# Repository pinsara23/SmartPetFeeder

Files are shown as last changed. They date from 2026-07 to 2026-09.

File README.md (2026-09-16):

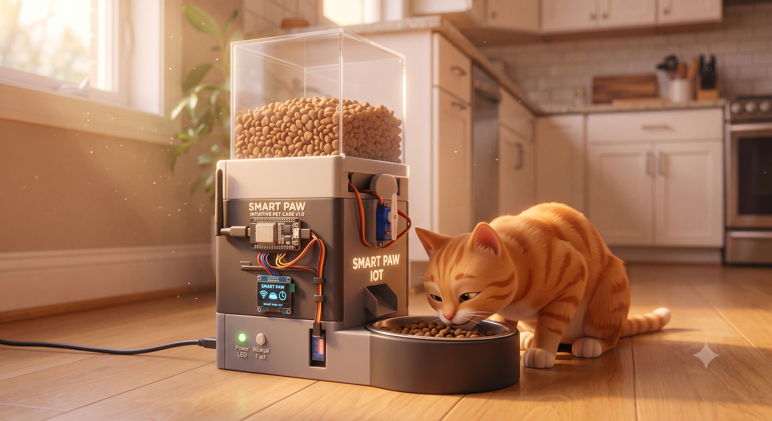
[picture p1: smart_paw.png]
Smart pet feeding system


# Smart Pet Feeder

A smart, automated pet feeding system built using an **ESP32** microcontroller. This project uses a load cell for precise food measurement, servos for dispensing, and a keypad-driven LCD menu for scheduling and portion control. 

The firmware is developed using **PlatformIO** and the Arduino framework.

## Features
- **Real-Time Clock:** Enter the current time in `HHMM` format during boot. The clock runs in firmware and wraps at midnight.
- **Precise Portion Control:** Enter a target weight from 1 to 1000 g. The HX711 load cell controls the food-container servo until the measured amount is within 3 g of the target.
- **Scheduled Feeding:** Configure two daily feeding times, `F1` and `F2`.
- **Two-Stage Feeding:** Food is first dispensed into the measuring chamber, then released into the bowl by a separate servo.
- **RFID Authentication:** An RFID scan authorizes early release during the configured release window. Release also occurs automatically at the exact scheduled minute as a fail-safe.
- **Jam Recovery:** If the measured weight does not increase by at least 0.5 g for 2 seconds, the food gate performs an automatic shake sequence before resuming.
- **Interactive UI:** A 20x4 I2C LCD and 4x4 keypad provide the setup, scheduling, weight, and reset controls.

## Hardware Components
- ESP32 Development Board
- 20x4 I2C LCD Display
- 4x4 Matrix Keypad
- Load Cell + HX711 Amplifier
- PCA9685 I2C PWM Servo Driver
- 2x Servos (for the food container and measurement chamber)
- MFRC522 RFID Reader

## Pin Configuration (ESP32)

| Component | Pins Used |
| --- | --- |
| **PCA9685 (Servos)**  | I2C (SDA, SCL) |
| **Keypad Rows** | GPIO 32, 33, 2, 4 |
| **Keypad Cols** | GPIO 12, 13, 16, 17 |
| **HX711 (Load Cell)** | DT: GPIO 25, SCK: GPIO 26 |
| **RFID (MFRC522)** | SS: GPIO 5, RST: GPIO 15 |
| **LCD (I2C)** | SDA, SCL (Default I2C pins) |

## ESP32 Pinout

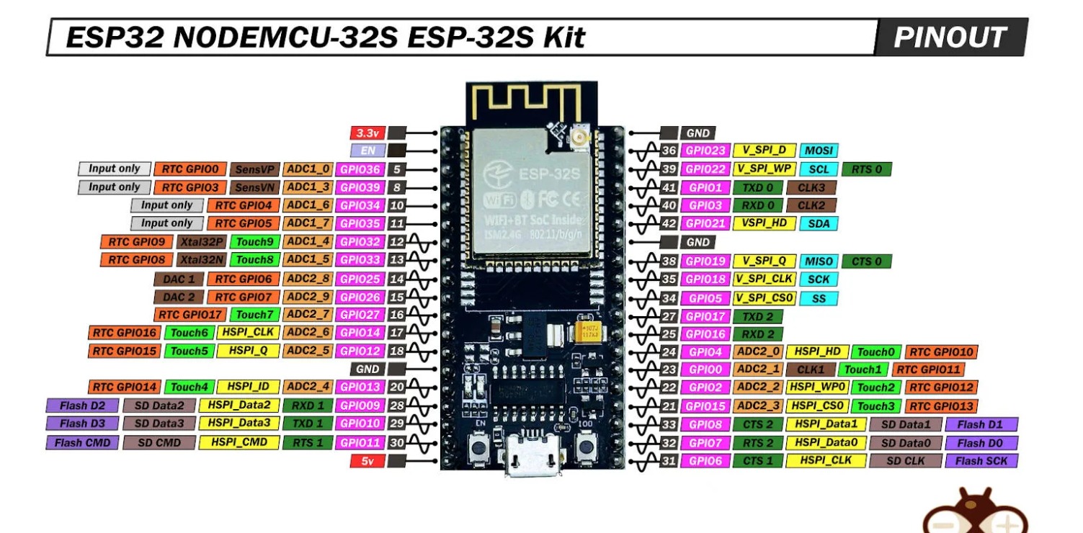
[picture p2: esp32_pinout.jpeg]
ESP32 pinout


## Software Dependencies
The following libraries are required (automatically managed via `platformio.ini`):
- `marcoschwartz/LiquidCrystal_I2C`
- `chris--a/Keypad`
- `bogde/HX711`
- `adafruit/Adafruit PWM Servo Driver Library`
- `miguelbalboa/MFRC522`

## Usage / Menu Navigation

1. **Boot:** Enter the current time (HHMM) using the keypad and press `#` to confirm.
2. **Dashboard (Default Screen):** Displays Target Weight (TW), Current Weight (CW), Feed Times (F1 & F2), and the current Time.
3. **Menu System:** Press `C` from the dashboard to enter the inputs menu.
   - **Press A:** Set Target Weight (1-1000 g). Enter the value and confirm with `#`.
   - **Press B:** Set Feed Times. Enter Feed 1 and Feed 2 in `HHMM` format, confirming each with `#`. Hours must be `00-23` and minutes must be `00-59`.
   - **Press C:** Go back to the dashboard.
   - **Press *:** Reset all settings and values at any time.

## Current Feeding Logic

The firmware treats each scheduled feeding as two separate operations:

1. **Fill the measuring chamber:**
   - **Feed 1:** The food-container servo dispenses from 3 to 5 minutes before the scheduled time.
   - **Feed 2:** The food-container servo dispenses from 35 to 90 minutes before the scheduled time.
   - Outside the active window, or when no target weight is configured, the food gate remains closed.
2. **Release food into the bowl:**
   - **Feed 1:** The chamber can open during the 2 minutes before feeding when RFID is detected.
   - **Feed 2:** The chamber can open during the 30 minutes before feeding when RFID is detected.
   - Once RFID has been detected in the release window, authorization remains active until that feeding event. At the exact scheduled time, the chamber opens even without RFID.

The schedule calculations support crossing midnight. Each feeding time is compared with the current time as minutes from midnight, and a feeding time that has passed is treated as the next day's event. Each RFID authorization flag is cleared after its release window ends, so an old scan cannot authorize a later feeding.

### Portion and Servo Control

- While more than 5 g remains, the food gate uses the normal 18-degree opening.
- With approximately 3 to 5 g remaining, it uses 10-degree pulses. Each pulse stays open for 120 ms, then the system waits 700 ms for the load cell reading to settle.
- When the measured amount is within 3 g of the target, dispensing stops and the food gate closes.
- During jam recovery, the gate alternates between 5 and 40 degrees for up to 6 steps, with 180 ms between steps, then returns to normal dispensing.
- The measuring-chamber servo is closed at 0 degrees and opened at 100 degrees.
- If dispensing is not currently scheduled, the food gate is closed and jam tracking is reset.
- The dispensing state machine reports `IDLE`, `NORMAL FLOW`, `PRECISION PULSE`, `SETTLING`, or `COMPLETE` through the serial monitor.

Weight readings are refreshed approximately every 150 ms using two HX711 samples. Negative readings are clamped to zero. The LCD dashboard shows the target weight, current weight, both feed times, current time, and the current dispensing status. At each scheduled minute, the firmware also prints a feed-time trigger message to the serial monitor.

## Calibration
Load cell calibration can be adjusted dynamically via the Serial Monitor at 115200 baud. The initial calibration factor is 1015.
- Send `+` to increase the calibration factor by 10.
- Send `-` to decrease the calibration factor by 10.

## Reset Behavior

Press `*` from any menu to clear the target weight, both feed times, and temporary input. The food gate and measuring chamber close, the dispensing state is reset, and the dashboard is displayed.

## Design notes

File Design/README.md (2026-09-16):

# 🐾 Smart PAW – Automatic Pet Feeder Mechanical Design

Smart PAW is an automated pet feeding system designed to dispense a predefined amount of food while controlling access to the feeding area.

This repository contains the mechanical/CAD design of the Smart PAW pet feeder.

The enclosure and internal mechanisms were designed to support the electronic components of the system, including:

- ESP32 microcontroller
- Load cells with HX711 modules
- Servo motors
- RFID reader
- PCA9685 servo controller
- 20×4 LCD display
- 4×4 keypad

The complete system combines embedded electronics, sensors, servo control, weight measurement, RFID access control, and mechanical design.

---

## 📸 Smart PAW CAD Design

Smart PAW CAD Design

The design contains three main sections:

1. Food Storage Container
2. Food Measuring / Dispensing Chamber
3. Pet Feeding Area

---

## 🏗️ Mechanical Design Overview

### 1. Food Storage Container

The upper section of the feeder acts as the main food storage hopper.

Food is stored here until the feeding process begins.

The bottom of the container guides the food toward the first servo-controlled gate.

        Food Storage
             │
             ▼
      Servo Controlled Gate
             │
             ▼
      Measuring Chamber

The sloped walls help guide food toward the dispensing opening using gravity.

---

### 2. First Servo Gate – Food Dispensing

A servo motor controls the opening between the food storage container and the measuring chamber.

When food is requested, the ESP32 gradually opens the servo gate.

Food falls into the measuring chamber while the system continuously monitors its weight.

The software uses different servo movements to improve dispensing accuracy and reduce food jams.

Features include:

- Small initial servo opening
- Gradual food dispensing
- Anti-jam servo movement
- Automatic stopping near the target weight

---

## ⚖️ Food Measuring Chamber

The middle section acts as the food measurement chamber.

Load cells installed underneath the chamber measure the amount of food that has been dispensed.

The load cells are connected to HX711 load-cell amplifier modules.

Food Hopper
     │
     ▼
Servo Gate
     │
     ▼
┌──────────────────┐
│ Measuring Chamber│
│                  │
│   Food + Weight  │
└──────────────────┘
        │
    Load Cells
        │
      HX711
        │
      ESP32

The ESP32 compares the measured weight with the target weight entered by the user.

For example:

Target Weight = 40 g

Current Weight = 10 g
→ Continue dispensing

Current Weight = 30 g
→ Reduce food flow

Current Weight = 38 g
→ Stop dispensing

A small tolerance is used so that the system does not continuously attempt to reach an exact measurement.

---

## 🔄 Anti-Jam Mechanism

Dry pet food can occasionally become stuck near the dispensing opening.

To reduce this problem, the feeder uses a software-controlled anti-jam mechanism.

If the measured weight does not increase sufficiently after opening the dispensing gate, the servo performs small repeated movements.

Open
 ↓
Check Weight
 ↓
No Significant Change
 ↓
Small Close / Open Movement
 ↓
Check Weight Again

This helps move food without requiring the user to manually shake the feeder.

---

## 3. Second Servo Gate – Food Release

After the required amount of food has been measured, a second servo-controlled gate releases the food.

The food falls from the measuring chamber onto the lower feeding tray/chute.

Measuring Chamber
        │
        ▼
 Second Servo Gate
        │
        ▼
   Feeding Chute
        │
        ▼
      Pet Bowl

This separates the measurement process from the final feeding process.

---

## 🐕 RFID Controlled Access

The Smart PAW system also includes RFID-based access control.

An RFID tag can be attached to the pet's collar.

When an authorized RFID tag is detected, the system can allow access to the food area.

This can help prevent other pets from accessing food intended for a particular pet.

---

## 🧠 System Working Principle

The complete feeding process is:

User Enters Required Food Weight
                │
                ▼
         ESP32 Starts Feeding
                │
                ▼
      First Servo Gate Opens
                │
                ▼
      Food Enters Measuring Chamber
                │
                ▼
        Load Cells Measure Weight
                │
                ▼
      Target Weight Reached?
          │             │
         NO            YES
          │             │
          ▼             ▼
 Continue Dispensing   Stop Servo
          │             │
          │             ▼
          │      Open Second Gate
          │             │
          └─────────────▼
                   Food Released
                         │
                         ▼
                      Pet Bowl

---

## 🔧 Main Hardware

| Component | Purpose |
|---|---|
| ESP32 | Main system controller |
| HX711 | Load cell signal amplifier |
| Load Cells | Measure food weight |
| MG996R Servo | Control food gates |
| PCA9685 | Servo motor controller |
| RFID Reader | Identify authorized pet |
| RFID Tag | Pet identification |
| 20×4 I2C LCD | Display system information |
| 4×4 Keypad | Enter target food weight |
| 5V Power Supply | Power the system |

---

## ⚙️ Main Mechanical Components

The CAD design includes:

- Main outer enclosure
- Upper food storage hopper
- Sloped food guide
- Food dispensing opening
- First servo mounting location
- Food measuring chamber
- Load-cell mounting area
- Second servo mounting location
- Food release mechanism
- Lower feeding chute
- Electronics mounting areas
- Front and side structural panels

---

## 💡 Design Goals

The mechanical design was developed with several goals:

- Compact construction
- Gravity-assisted food movement
- Controlled food dispensing
- Accurate food measurement
- Reduced food jamming
- Easy servo integration
- Easy electronics installation
- Simple assembly
- Low-cost construction
- Automated pet access

---

## 📂 Suggested Repository Structure

Smart-PAW-Mechanical-Design/
│
├── README.md
│
├── CAD/
│   ├── parts/
│   └── assembly/
│
├── STL/
│   └── printable-parts/
│
├── drawings/
│   └── technical-drawings/
│
├── images/
│   ├── smart-paw-design.jpg
│   ├── front-view.jpg
│   ├── side-view.jpg
│   └── assembly-view.jpg
│
└── docs/
    └── design-notes.md

The exact folders can be changed depending on which CAD, STL, STEP, or drawing files are available.

---

## 🚀 Future Improvements

Possible future improvements include:

- Improved food-flow geometry
- Modular removable food container
- Easier cleaning mechanism
- Improved servo gate design
- Fully 3D-printable components
- Additional load-cell support
- Improved RFID antenna placement
- Adjustable feeding tray
- Enclosure for electronic components
- Detection of low food level
- Mobile application integration
- Wi-Fi based feeding control
- Feeding history and statistics

---

## 🔗 Related Smart PAW Development

The mechanical design is only one part of the complete Smart PAW project.

The overall system combines:

Mechanical Design
       +
ESP32 Firmware
       +
Weight Measurement
       +
Servo Control
       +
RFID Identification
       +
User Interface
       =
   Smart PAW

---

## 🎯 Project Purpose

Smart PAW was developed as a practical embedded systems project that combines mechanical design, electronics, sensors, actuators, and software into a single automated pet feeding system.

The project demonstrates concepts including:

- Embedded system development
- ESP32 programming
- Sensor interfacing
- Load-cell measurement
- Closed-loop control
- Servo motor control
- RFID identification
- Mechanical CAD design
- Hardware/software integration

---

## 👨‍💻 Author

Pinsara Sarathchandra

Computer Engineering Undergraduate

---

## 📜 License

This project is intended for educational and research purposes.

If you plan to reuse or modify the design, please provide appropriate credit to the original project.

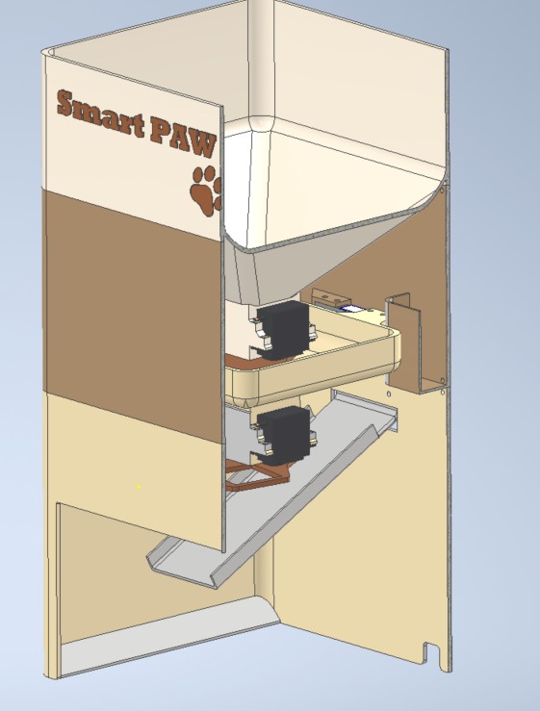
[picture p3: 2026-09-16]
Design/images/side_view_cut.jpeg

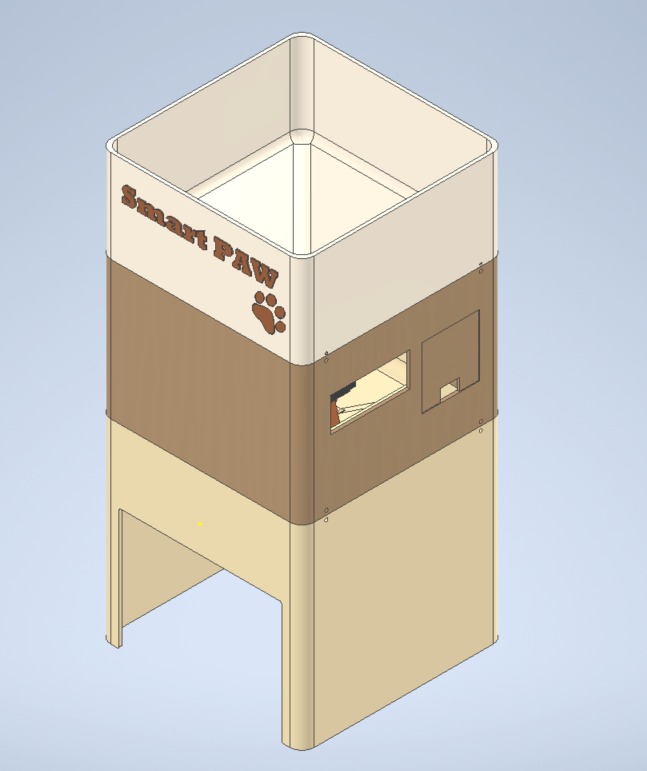
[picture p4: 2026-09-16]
Design/images/side_view.jpeg

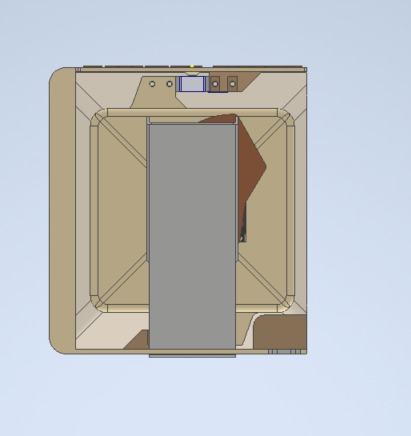
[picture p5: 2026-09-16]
Design/images/bottom_view.jpeg

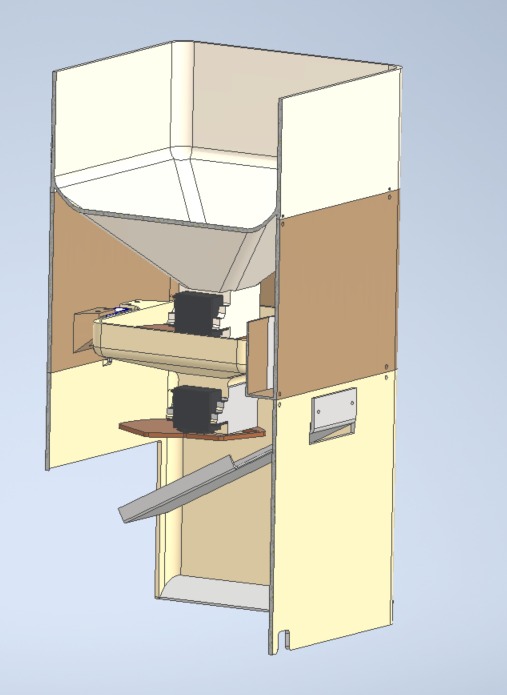
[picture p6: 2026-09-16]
Design/images/detailed_view.jpeg

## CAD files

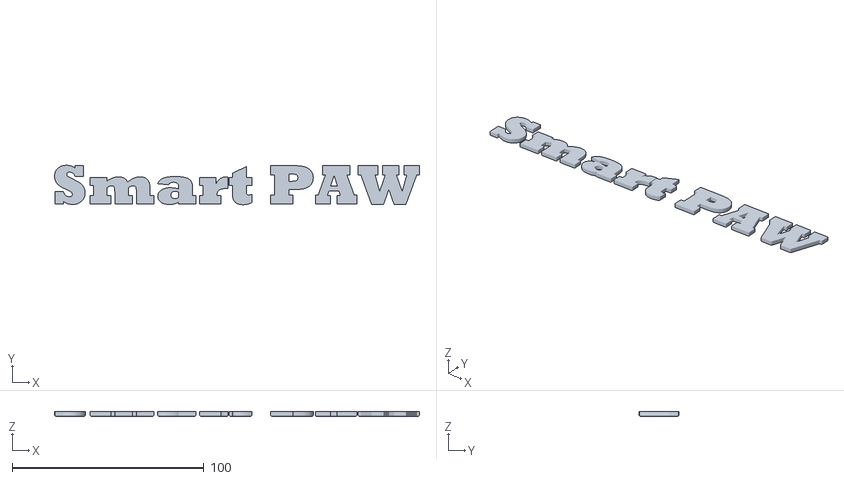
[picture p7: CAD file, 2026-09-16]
Design/stl/P1_name.stl
190.2 x 20.7 x 2.40

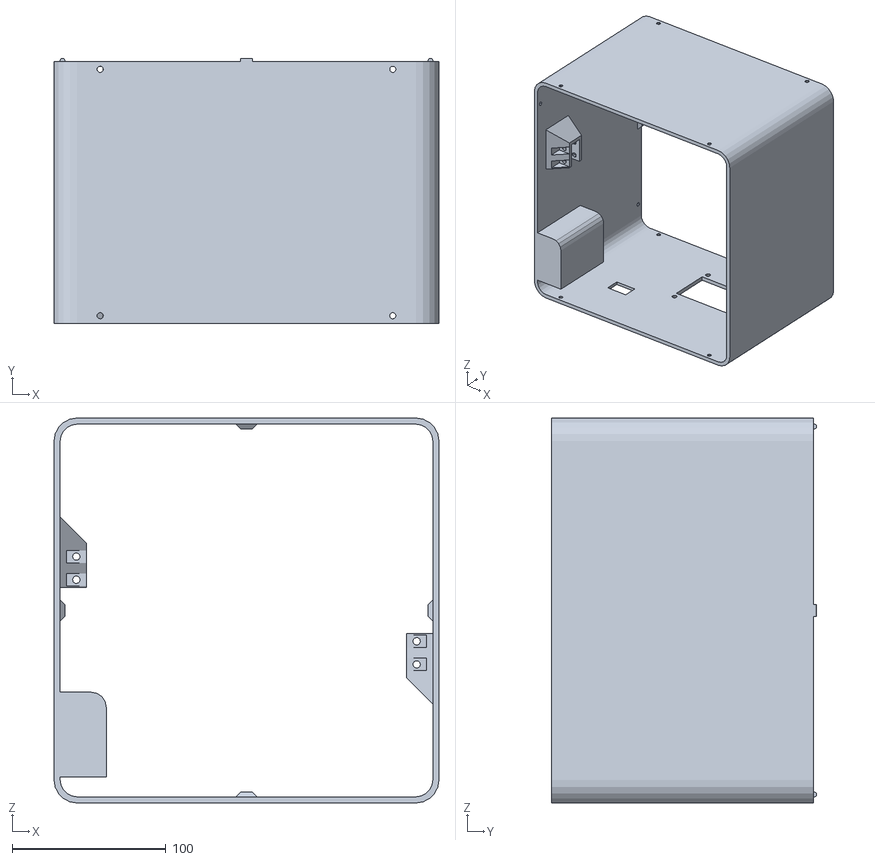
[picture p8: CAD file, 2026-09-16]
Design/stl/P1_middle.stl
250.0 x 172.0 x 250.0

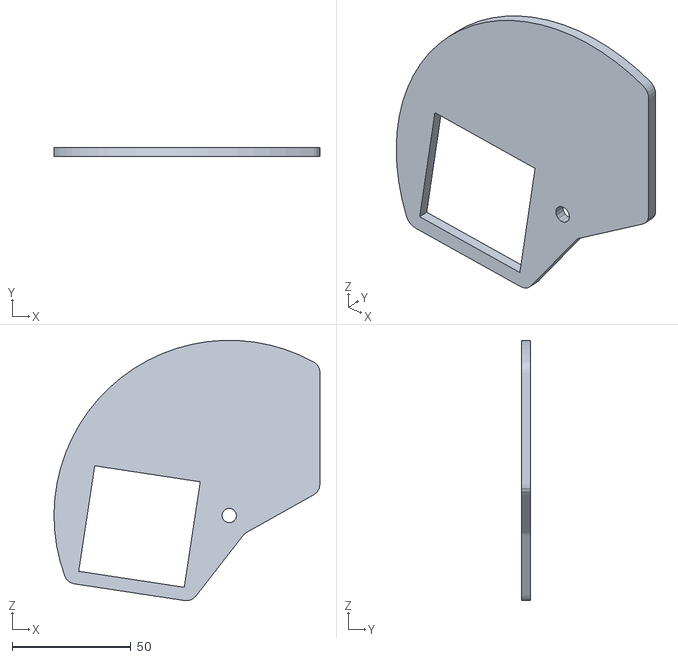
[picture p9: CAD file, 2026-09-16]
Design/stl/Servo_Lid.stl
112.2 x 4.00 x 109.7

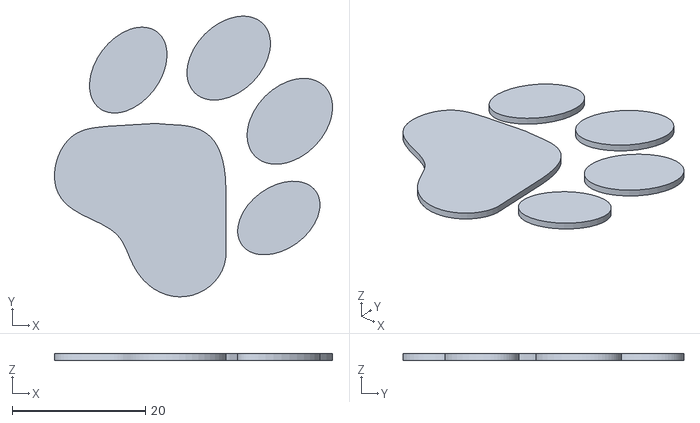
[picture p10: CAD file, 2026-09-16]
Design/stl/paw.stl
41.8 x 42.2 x 1.00

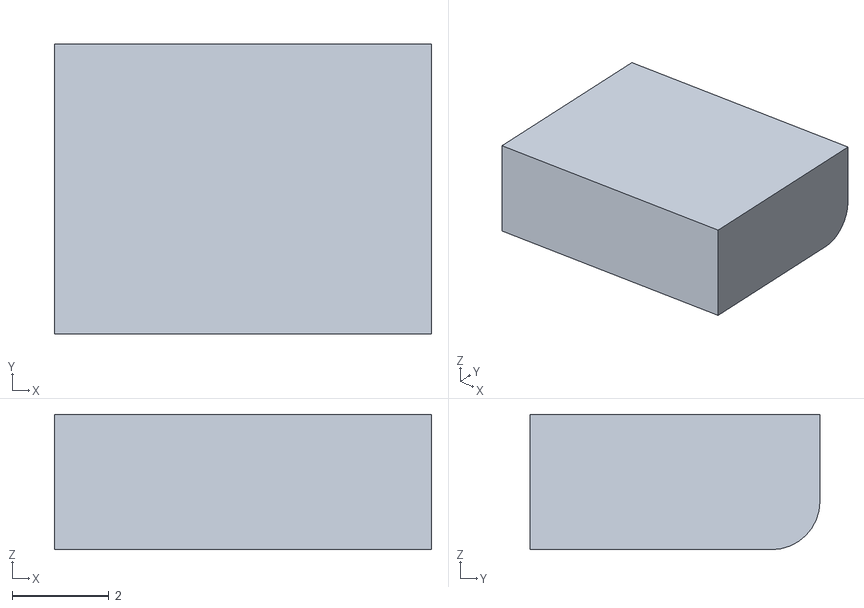
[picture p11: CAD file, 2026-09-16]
Design/stl/holder(x3).stl
7.80 x 6.00 x 2.80

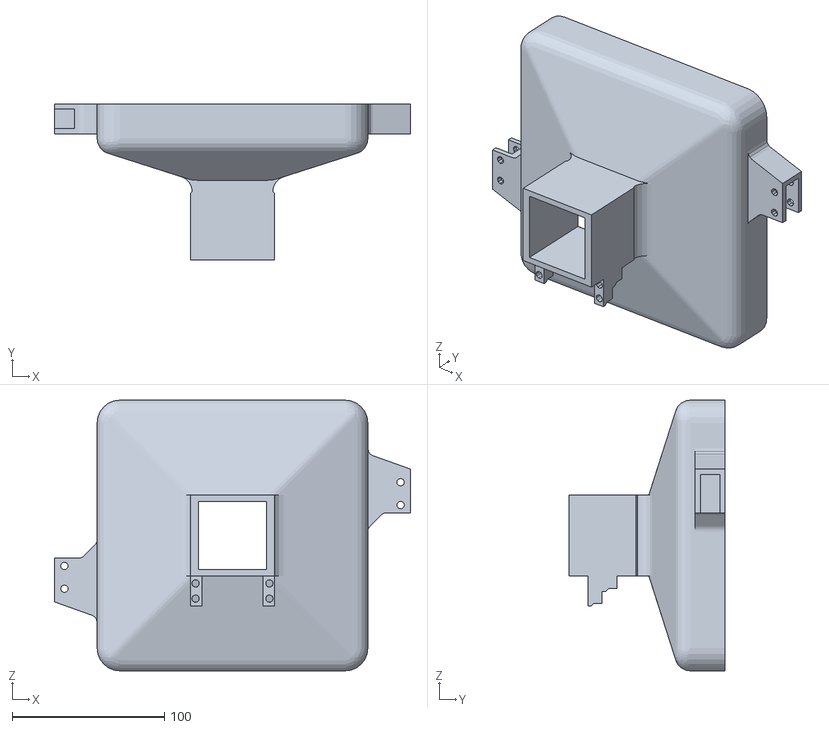
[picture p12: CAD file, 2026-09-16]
Design/stl/P2_middle.stl
234.0 x 102.3 x 178.0

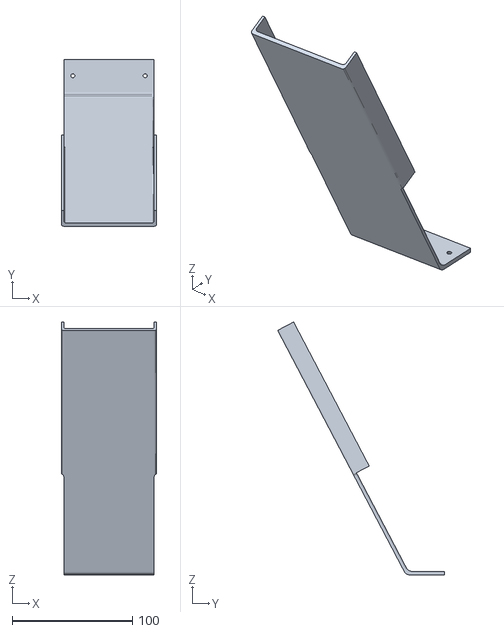
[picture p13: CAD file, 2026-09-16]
Design/stl/slide.stl
79.0 x 138.4 x 210.0

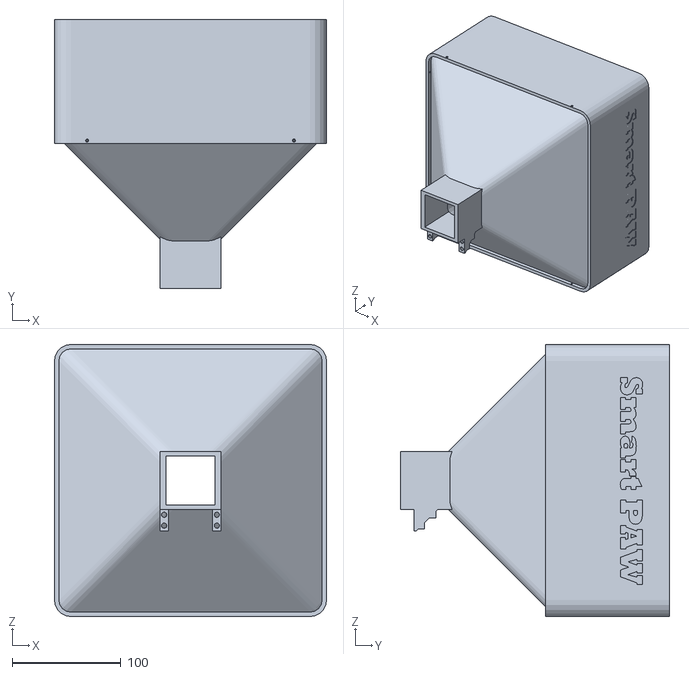
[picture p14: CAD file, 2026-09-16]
Design/stl/P1_up.stl
250.0 x 247.3 x 250.0

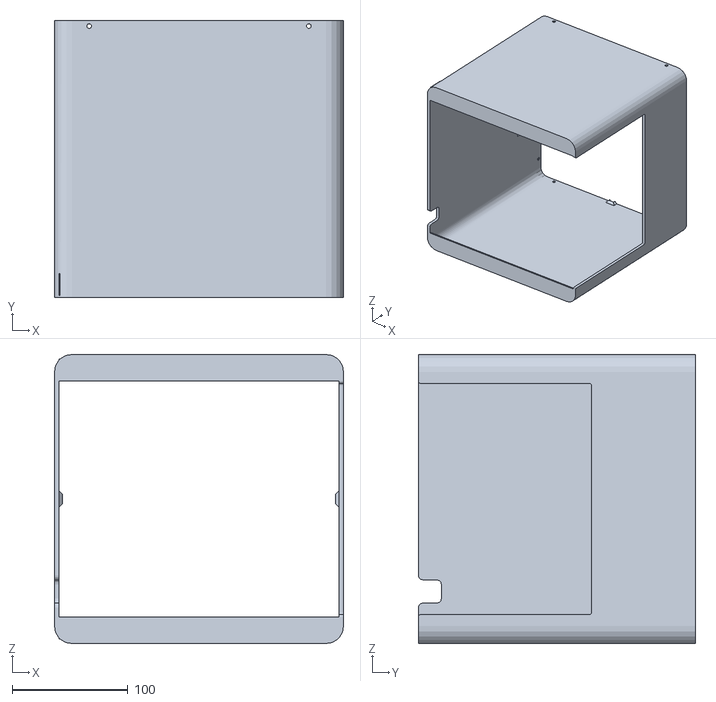
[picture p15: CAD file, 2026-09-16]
Design/stl/P1_Down.stl
250.0 x 240.0 x 250.0

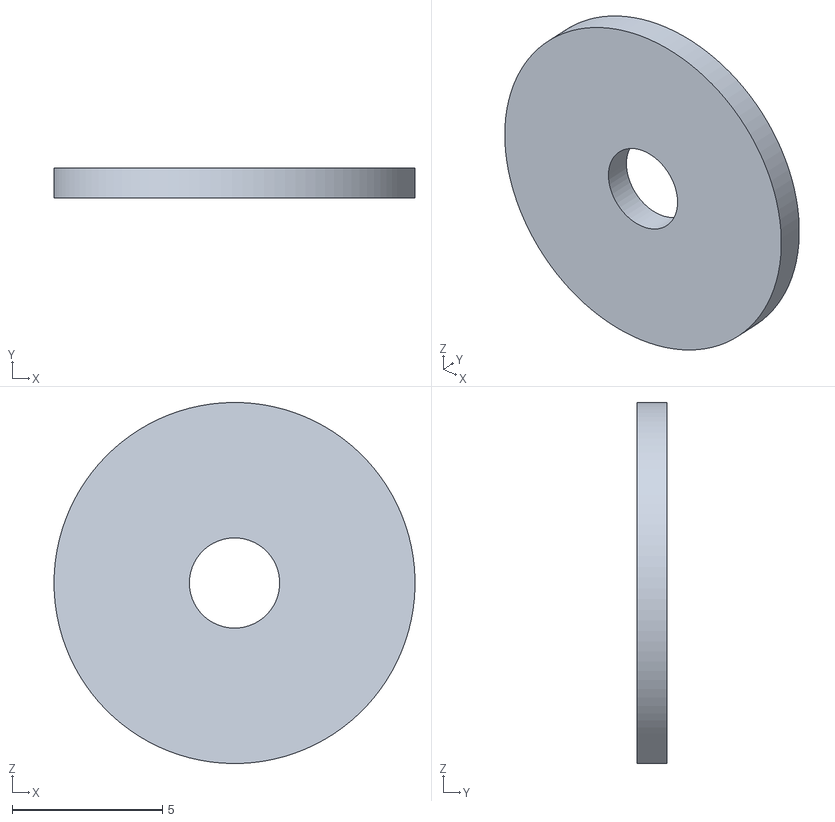
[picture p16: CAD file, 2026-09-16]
Design/stl/washer_for_P3_Lid.stl
12.0 x 1.00 x 12.0

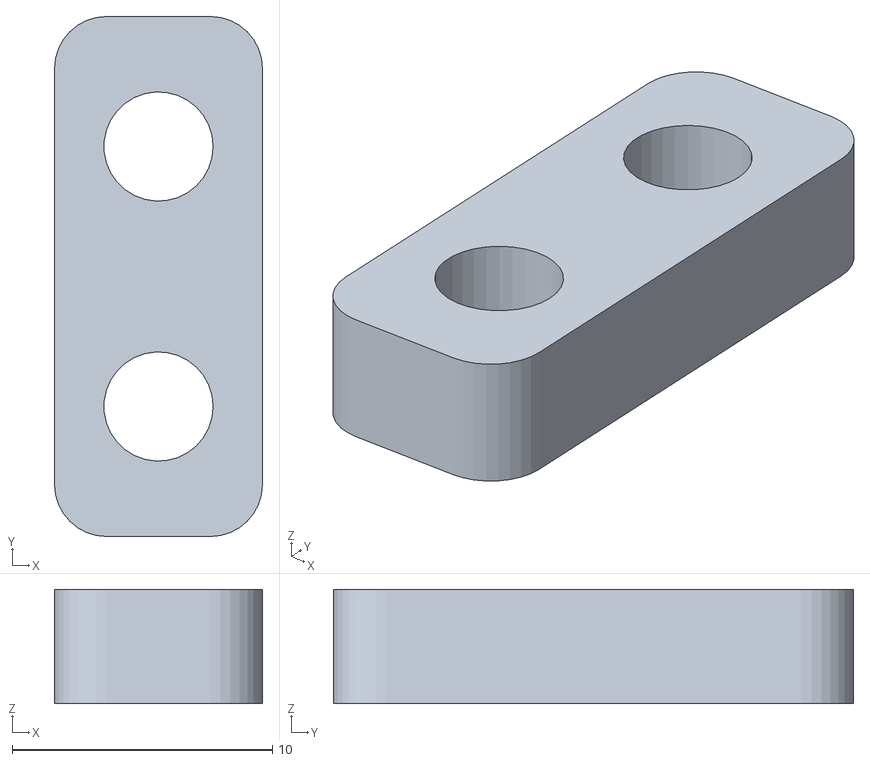
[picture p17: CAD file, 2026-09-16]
Design/stl/screw(x15).stl
8.00 x 20.0 x 4.40

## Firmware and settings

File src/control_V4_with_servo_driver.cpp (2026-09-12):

#include <Wire.h>
#include <LiquidCrystal_I2C.h>
#include <Keypad.h>
#include "HX711.h"
#include <Adafruit_PWMServoDriver.h>
#include <SPI.h>
#include <MFRC522.h>


// ============================================================
// RFID
// ============================================================

const int RST_PIN = 15;
const int SS_PIN = 5;

MFRC522 mfrc522(SS_PIN, RST_PIN);


// ============================================================
// PCA9685 SERVO DRIVER
// ============================================================

Adafruit_PWMServoDriver pwm = Adafruit_PWMServoDriver();

const int foodContainerPin = 0;
const int measureChamberPin = 1;


// Convert servo angle to PCA9685 pulse
int angleToPulse(int angle)
{
    return map(angle, 0, 180, 102, 491);
}


// ============================================================
// FOOD CONTAINER SERVO SETTINGS
// ============================================================

const int FOOD_CLOSED_ANGLE = 0;

// Normal small opening
const int FOOD_NORMAL_ANGLE = 18;

// Small opening for final dispensing
const int FOOD_PULSE_ANGLE = 10;


// ============================================================
// ANTI-JAM SETTINGS
// ============================================================

const int SHAKE_OPEN_ANGLE = 40;
const int SHAKE_CLOSE_ANGLE = 5;

const unsigned long SHAKE_STEP_TIME = 180;

const int MAX_SHAKE_STEPS = 6;


// ============================================================
// MEASURING CHAMBER SERVO
// ============================================================

const int measureChamberOpenAngle = 100;
const int measureChamberCloseAngle = 0;


// ============================================================
// DISPENSING SETTINGS
// ============================================================

// Enter precision mode when 5 g remains
const float PRECISION_MARGIN = 5.0;


// IMPORTANT:
// If target-current <= 3g,
// consider the amount acceptable.
const float TARGET_TOLERANCE = 3.0;


// Precision pulse duration
const unsigned long PULSE_OPEN_TIME = 120;


// Wait for food/load cell to settle
const unsigned long SETTLE_TIME = 700;


// ============================================================
// JAM DETECTION
// ============================================================

const float MIN_WEIGHT_PROGRESS = 0.5;

const unsigned long JAM_DETECT_TIME = 2000;


float lastProgressWeight = 0.0;

unsigned long lastProgressTime = 0;


bool clearingJam = false;

int shakeStep = 0;

unsigned long shakeTimer = 0;


// ============================================================
// DISPENSING STATE
// ============================================================

enum DispenseState
{
    DISPENSE_IDLE,
    DISPENSE_NORMAL,
    DISPENSE_PULSE_OPEN,
    DISPENSE_SETTLING,
    DISPENSE_COMPLETE
};


DispenseState dispenseState = DISPENSE_IDLE;

unsigned long dispenseTimer = 0;


// ============================================================
// LCD
// ============================================================

LiquidCrystal_I2C lcd(0x27, 20, 4);


// ============================================================
// KEYPAD
// ============================================================

const byte ROWS = 4;
const byte COLS = 4;


char hexaKeys[ROWS][COLS] =
{
    {'1', '2', '3', 'A'},
    {'4', '5', '6', 'B'},
    {'7', '8', '9', 'C'},
    {'*', '0', '#', 'D'}
};


byte rowPins[ROWS] =
{
    32, 33, 2, 4
};


byte colPins[COLS] =
{
    12, 13, 16, 17
};


Keypad customKeypad =
    Keypad(
        makeKeymap(hexaKeys),
        rowPins,
        colPins,
        ROWS,
        COLS
    );


// ============================================================
// HX711
// ============================================================

#define DT 25
#define SCK 26


HX711 scale;

float calibration_factor = 1015;


// ============================================================
// CLOCK
// ============================================================

int hours = 18;
int minutes = 23;
int seconds = 0;

unsigned long lastSecondUpdate = 0;


// ============================================================
// WEIGHT UPDATE
// ============================================================

unsigned long lastWeightUpdate = 0;

const unsigned long WEIGHT_UPDATE_INTERVAL = 150;


// ============================================================
// LCD UPDATE
// ============================================================

unsigned long lastLCDUpdate = 0;

const unsigned long LCD_UPDATE_INTERVAL = 500;


// ============================================================
// SERIAL UPDATE
// ============================================================

unsigned long lastSerialUpdate = 0;

const unsigned long SERIAL_UPDATE_INTERVAL = 1000;


// ============================================================
// WEIGHT VARIABLES
// ============================================================

String inputWeight = "";

int targetWeight = 0;

float currentWeightDisplay = 0.0;


// ============================================================
// MENU STATE
// ============================================================

enum MenuState
{
    INITIAL_TIME_SETUP,
    DEFAULT_SCREEN,
    INPUTS_MENU,
    WEIGHT_INPUT,
    TIME_SLOT_1,
    TIME_SLOT_2
};


MenuState currentState = INITIAL_TIME_SETUP;


// Feeding times in minutes from midnight
int feedTime1 = -1;
int feedTime2 = -1;


String inputTime = "";


// ============================================================
// FOOD SERVO
// ============================================================

void setFoodGate(int angle)
{
    static int previousAngle = -1;

    if (angle != previousAngle)
    {
        pwm.setPWM(
            foodContainerPin,
            0,
            angleToPulse(angle)
        );

        previousAngle = angle;

        Serial.print("Food Servo: ");
        Serial.print(angle);
        Serial.println(" deg");
    }
}


// ============================================================
// MEASURING CHAMBER SERVO
// ============================================================

void setMeasureChamber(int angle)
{
    static int previousAngle = -1;

    if (angle != previousAngle)
    {
        pwm.setPWM(
            measureChamberPin,
            0,
            angleToPulse(angle)
        );

        previousAngle = angle;

        Serial.print("Measure Servo: ");
        Serial.print(angle);
        Serial.println(" deg");
    }
}


// ============================================================
// DISPLAY TIME
// ============================================================

void displayTimeOnLCD()
{
    if (
        currentState == DEFAULT_SCREEN ||
        currentState == INITIAL_TIME_SETUP
    )
    {
        return;
    }


    lcd.setCursor(0, 3);


    if (hours < 10)
        lcd.print("0");

    lcd.print(hours);

    lcd.print(":");


    if (minutes < 10)
        lcd.print("0");

    lcd.print(minutes);

    lcd.print(":");


    if (seconds < 10)
        lcd.print("0");

    lcd.print(seconds);


    lcd.print("        ");
}


// ============================================================
// DEFAULT SCREEN
// ============================================================

void updateDefaultScreen(float currentWeight)
{
    // Row 0
    lcd.setCursor(0, 0);

    lcd.print("TW:");
    lcd.print(targetWeight);
    lcd.print("g    ");


    lcd.setCursor(10, 0);

    lcd.print("CW:");
    lcd.print(currentWeight, 1);
    lcd.print("g   ");


    // Row 1
    lcd.setCursor(0, 1);

    lcd.print("F1:");


    if (feedTime1 >= 0)
    {
        if ((feedTime1 / 60) < 10)
            lcd.print("0");

        lcd.print(feedTime1 / 60);

        lcd.print(":");

        if ((feedTime1 % 60) < 10)
            lcd.print("0");

        lcd.print(feedTime1 % 60);
    }
    else
    {
        lcd.print("--:--");
    }


    lcd.print("  ");


    lcd.setCursor(10, 1);

    lcd.print("F2:");


    if (feedTime2 >= 0)
    {
        if ((feedTime2 / 60) < 10)
            lcd.print("0");

        lcd.print(feedTime2 / 60);

        lcd.print(":");

        if ((feedTime2 % 60) < 10)
            lcd.print("0");

        lcd.print(feedTime2 % 60);
    }
    else
    {
        lcd.print("--:--");
    }


    // Row 2
    lcd.setCursor(0, 2);

    lcd.print("Time: ");


    if (hours < 10)
        lcd.print("0");

    lcd.print(hours);

    lcd.print(":");


    if (minutes < 10)
        lcd.print("0");

    lcd.print(minutes);

    lcd.print(":");


    if (seconds < 10)
        lcd.print("0");

    lcd.print(seconds);

    lcd.print("      ");


    // Row 3
    lcd.setCursor(0, 3);


    if (clearingJam)
    {
        lcd.print("Clearing food jam ");
    }

    else if (
        targetWeight > 0 &&
        currentWeight >= targetWeight - TARGET_TOLERANCE
    )
    {
        lcd.print("Food ready!        ");
    }

    else
    {
        lcd.print("Press C for inputs ");
    }
}


// ============================================================
// INITIAL TIME SCREEN
// ============================================================

void showInitialTimeSetup()
{
    lcd.clear();


    lcd.setCursor(0, 0);
    lcd.print("Set Current Time:");


    lcd.setCursor(0, 1);
    lcd.print("HHMM: ");
    lcd.print(inputTime);


    lcd.setCursor(0, 3);
    lcd.print("Press # to confirm");
}


// ============================================================
// DEFAULT SCREEN
// ============================================================

void showDefaultScreen()
{
    updateDefaultScreen(currentWeightDisplay);
}


// ============================================================
// INPUTS MENU
// ============================================================

void showInputsMenu()
{
    lcd.clear();


    lcd.setCursor(0, 0);
    lcd.print("A: Set Weight");


    lcd.setCursor(0, 1);
    lcd.print("B: Set Feed Times");


    lcd.setCursor(0, 2);
    lcd.print("C: Back  *: Reset");


    displayTimeOnLCD();
}


// ============================================================
// WEIGHT INPUT
// ============================================================

void showWeightInput()
{
    lcd.clear();


    lcd.setCursor(0, 0);
    lcd.print("Enter Weight (g):");


    lcd.setCursor(0, 1);
    lcd.print("Input: ");

    lcd.print(inputWeight);

    lcd.print("g      ");


    lcd.setCursor(0, 2);
    lcd.print("Press # to confirm");


    displayTimeOnLCD();
}


// ============================================================
// FEED TIME INPUT
// ============================================================

void showTimeInput(int slot)
{
    lcd.clear();


    lcd.setCursor(0, 0);

    lcd.print("Feed Time ");

    lcd.print(slot);

    lcd.print(" (HHMM):");


    lcd.setCursor(0, 1);

    lcd.print("Input: ");

    lcd.print(inputTime);

    lcd.print("      ");


    lcd.setCursor(0, 2);

    lcd.print("Press # to confirm");


    displayTimeOnLCD();
}


// ============================================================
// FEED TIME CONFIRM
// ============================================================

void showTimeConfirmed(int slot, int h, int m)
{
    lcd.clear();


    lcd.setCursor(0, 0);

    lcd.print("Feed Time ");

    lcd.print(slot);

    lcd.print(" Set!");


    lcd.setCursor(0, 1);


    if (h < 10)
        lcd.print("0");


    lcd.print(h);

    lcd.print(":");


    if (m < 10)
        lcd.print("0");


    lcd.print(m);


    delay(1000);
}


// ============================================================
// RESET DISPENSING
// ============================================================

void resetDispensingSystem()
{
    dispenseState = DISPENSE_IDLE;

    clearingJam = false;

    shakeStep = 0;

    lastProgressWeight = currentWeightDisplay;

    lastProgressTime = millis();

    setFoodGate(FOOD_CLOSED_ANGLE);
}


// ============================================================
// FULL RESET
// ============================================================

void resetAll()
{
    inputWeight = "";

    targetWeight = 0;

    feedTime1 = -1;
    feedTime2 = -1;

    inputTime = "";

    currentState = DEFAULT_SCREEN;


    resetDispensingSystem();


    setMeasureChamber(
        measureChamberCloseAngle
    );


    lcd.clear();


    lcd.setCursor(0, 0);

    lcd.print("System Reset!");


    lcd.setCursor(0, 1);

    lcd.print("Values cleared");


    delay(1000);


    showDefaultScreen();
}


// ============================================================
// CHECK FEED TIMES
// ============================================================

void checkFeedingTime()
{
    int currentMinutes =
        hours * 60 + minutes;


    if (
        feedTime1 >= 0 &&
        currentMinutes == feedTime1 &&
        seconds == 0
    )
    {
        Serial.println("FEED TIME 1 TRIGGERED!");
    }


    if (
        feedTime2 >= 0 &&
        currentMinutes == feedTime2 &&
        seconds == 0
    )
    {
        Serial.println("FEED TIME 2 TRIGGERED!");
    }
}


// ============================================================
// AUTOMATIC JAM CLEARING
// ============================================================
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
void loop()
{
    // ========================================================
    // KEYPAD
    // ========================================================

    char key =
        customKeypad.getKey();


    if (
        key
    )
    {
        // Global reset
        if (
            key == '*'
        )
        {
            resetAll();

            return;
        }


        switch (
            currentState
        )
        {
            // =================================================
            // INITIAL TIME
            // =================================================

            case INITIAL_TIME_SETUP:
            {
                if (
                    key >= '0' &&
                    key <= '9'
                )
                {
                    if (
                        inputTime.length() <
                        4
                    )
                    {
                        inputTime +=
                            key;
                    }


                    lcd.setCursor(
                        6,
                        1
                    );


                    lcd.print(
                        inputTime
                    );


                    lcd.print(
                        "      "
                    );
                }


                else if (
                    key == '#'
                )
                {
                    if (
                        inputTime.length() ==
                        4
                    )
                    {
                        int h =
                            inputTime.substring(
                                0,
                                2
                            ).toInt();


                        int m =
                            inputTime.substring(
                                2,
                                4
                            ).toInt();


                        if (
                            h >= 0 &&
                            h <= 23 &&
                            m >= 0 &&
                            m <= 59
                        )
                        {
                            hours =
                                h;


                            minutes =
                                m;


                            seconds =
                                0;


                            lcd.clear();


                            lcd.setCursor(
                                0,
                                0
                            );


                            lcd.print(
                                "Time Set!"
                            );


                            delay(
                                1000
                            );


                            inputTime =
                                "";


                            currentState =
                                DEFAULT_SCREEN;


                            showDefaultScreen();
                        }

                        else
                        {
                            lcd.setCursor(
                                0,
                                2
                            );


                            lcd.print(
                                "Invalid Time!"
                            );


                            delay(
                                1000
                            );


                            inputTime =
                                "";


                            showInitialTimeSetup();
                        }
                    }

                    else
                    {
                        lcd.setCursor(
                            0,
                            2
                        );


                        lcd.print(
                            "Enter 4 digits!"
                        );


                        delay(
                            1000
                        );


                        inputTime =
                            "";


                        showInitialTimeSetup();
                    }
                }


                break;
            }


            // =================================================
            // DEFAULT SCREEN
            // =================================================

            case DEFAULT_SCREEN:
            {
                if (
                    key == 'C'
                )
                {
                    currentState =
                        INPUTS_MENU;


                    showInputsMenu();
                }


                break;
            }


            // =================================================
            // INPUT MENU
            // =================================================

            case INPUTS_MENU:
            {
                if (
                    key == 'A'
                )
                {
                    currentState =
                        WEIGHT_INPUT;


                    inputWeight =
                        "";


                    showWeightInput();
                }


                else if (
                    key == 'B'
                )
                {
                    currentState =
                        TIME_SLOT_1;


                    inputTime =
                        "";


                    showTimeInput(
                        1
                    );
                }


                else if (
                    key == 'C'
                )
                {
                    currentState =
                        DEFAULT_SCREEN;


                    showDefaultScreen();
                }


                break;
            }


            // =================================================
            // WEIGHT INPUT
            // =================================================

            case WEIGHT_INPUT:
            {
                if (
                    key >= '0' &&
                    key <= '9'
                )
                {
                    if (
                        inputWeight.length() <
                        4
                    )
                    {
                        inputWeight +=
                            key;
                    }


                    lcd.setCursor(
                        0,
                        1
                    );


                    lcd.print(
                        "Input: "
                    );


                    lcd.print(
                        inputWeight
                    );


                    lcd.print(
                        "g      "
                    );
                }


                else if (
                    key == '#'
                )
                {
                    int value =
                        inputWeight.toInt();


                    if (
                        value >= 1 &&
                        value <= 1000
                    )
                    {
                        targetWeight =
                            value;


                        resetDispensingSystem();


                        lcd.setCursor(
                            0,
                            1
                        );


                        lcd.print(
                            "Target: "
                        );


                        lcd.print(
                            targetWeight
                        );


                        lcd.print(
                            "g      "
                        );


                        Serial.print(
                            "Target set: "
                        );


                        Serial.print(
                            targetWeight
                        );


                        Serial.println(
                            " g"
                        );


                        delay(
                            1000
                        );
                    }

                    else
                    {
                        lcd.setCursor(
                            0,
                            1
                        );


                        lcd.print(
                            "Invalid Range!"
                        );


                        delay(
                            1000
                        );
                    }


                    inputWeight =
                        "";


                    currentState =
                        DEFAULT_SCREEN;


                    showDefaultScreen();
                }


                break;
            }
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

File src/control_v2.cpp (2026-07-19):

// #include <Wire.h>
// #include <LiquidCrystal_I2C.h>
// #include <Keypad.h>
// #include "HX711.h"
// #include <ESP32Servo.h>

// Servo foodContainerServo;
// Servo measureChamberServo;

// const int foodContainerServoPin = 33;
// const int measureChamberServoPin = 32;

// // ---------------- Servo Angles ----------------
// int servoOpenAngle = 90;
// int servoCloseAngle = 0;
// int measureChamberOpenAngle = 90;
// int measureChamberCloseAngle = 0;


// // ---------------- LCD Configuration ----------------
// LiquidCrystal_I2C lcd(0x27, 20, 4);

// // ---------------- Keypad Configuration ----------------
// const byte ROWS = 4;
// const byte COLS = 4;

// char hexaKeys[ROWS][COLS] = {
//   {'1','2','3','A'},
//   {'4','5','6','B'},
//   {'7','8','9','C'},
//   {'*','0','#','D'}
// };

// byte rowPins[ROWS] = {2, 0, 4, 16};
// byte colPins[COLS] = {17, 5, 18, 19};

// Keypad customKeypad = Keypad(makeKeymap(hexaKeys), rowPins, colPins, ROWS, COLS);

// // ---------------- HX711 Configuration ----------------
// #define DT 23
// #define SCK 26

// HX711 scale;

// // Calibration factor
// float calibration_factor = 1015;

// // ---------------- Time Variables ----------------
// int hours = 18;
// int minutes = 23;
// int seconds = 0;

// unsigned long lastUpdate = 0;

// // ---------------- Weight Variables ----------------
// String inputWeight = "";
// int targetWeight = 0;
// float currentWeightDisplay = 0.0;

// // ---------------- Feeding Time Variables ----------------
// // State machine for menu navigation
// enum MenuState {
//   INITIAL_TIME_SETUP, // Setup current time on boot
//   DEFAULT_SCREEN, // Main default dashboard
//   INPUTS_MENU,    // Show "A: Set Weight, B: Set Time"
//   WEIGHT_INPUT,   // Entering weight (numbers + # to confirm)
//   TIME_SLOT_1,    // Entering first feeding time (HHMM + # to confirm)
//   TIME_SLOT_2     // Entering second feeding time (HHMM + # to confirm)
// };

// MenuState currentState = INITIAL_TIME_SETUP;

// // Feeding time slots (stored as minutes from midnight for easy comparison)
// int feedTime1 = -1;  // -1 means not set
// int feedTime2 = -1;  // -1 means not set

// // Temporary variables for time input
// String inputTime = "";
// int timeInputStage = 0;  // 0 = entering hours, 1 = entering minutes
// int tempHours = 0;
// int tempMinutes = 0;

// // ---------------- Display Time Function ----------------
// void displayTimeOnLCD() {
//   if (currentState == DEFAULT_SCREEN || currentState == INITIAL_TIME_SETUP) return;

//   lcd.setCursor(0, 3);

//   if (hours < 10) lcd.print("0");
//   lcd.print(hours);

//   lcd.print(":");

//   if (minutes < 10) lcd.print("0");
//   lcd.print(minutes);

//   lcd.print(":");

//   if (seconds < 10) lcd.print("0");
//   lcd.print(seconds);

//   lcd.print("        ");
// }

// void updateDefaultScreen(float currentWeight) {
//   // Row 0
//   lcd.setCursor(0, 0);
//   lcd.print("TW:");
//   lcd.print(targetWeight);
//   lcd.print("g    "); // Clear old digits

//   lcd.setCursor(10, 0);
//   lcd.print("CW:");
//   lcd.print(currentWeight, 1);
//   lcd.print("g    "); // Clear old digits

//   // Row 1
//   lcd.setCursor(0, 1);
//   lcd.print("F1:");
//   if (feedTime1 >= 0) {
//     if (feedTime1 / 60 < 10) lcd.print("0");
//     lcd.print(feedTime1 / 60);
//     lcd.print(":");
//     if (feedTime1 % 60 < 10) lcd.print("0");
//     lcd.print(feedTime1 % 60);
//   } else {
//     lcd.print("--:--");
//   }
//   lcd.print("  ");

//   lcd.setCursor(10, 1);
//   lcd.print("F2:");
//   if (feedTime2 >= 0) {
//     if (feedTime2 / 60 < 10) lcd.print("0");
//     lcd.print(feedTime2 / 60);
//     lcd.print(":");
//     if (feedTime2 % 60 < 10) lcd.print("0");
//     lcd.print(feedTime2 % 60);
//   } else {
//     lcd.print("--:--");
//   }
//   lcd.print("  ");

//   // Row 2
//   lcd.setCursor(0, 2);
//   lcd.print("Time: ");
//   if (hours < 10) lcd.print("0"); lcd.print(hours); lcd.print(":");
//   if (minutes < 10) lcd.print("0"); lcd.print(minutes); lcd.print(":");
//   if (seconds < 10) lcd.print("0"); lcd.print(seconds);
//   lcd.print("      ");

//   // Row 3
//   lcd.setCursor(0, 3);
//   if (targetWeight > 0 && currentWeight > targetWeight) {
//     lcd.print("OVERLOAD! Press C   ");
//   } else {
//     lcd.print("Press C for inputs  ");
//   }
// }

// // ---------------- Helper Functions ----------------
// void showInitialTimeSetup() {
//   lcd.clear();
//   lcd.setCursor(0, 0);
//   lcd.print("Set Current Time:");
//   lcd.setCursor(0, 1);
//   lcd.print("HHMM: ");
//   lcd.print(inputTime);
//   lcd.print("      ");
//   lcd.setCursor(0, 3);
//   lcd.print("Press # to confirm");
// }

// void showDefaultScreen() {
//   updateDefaultScreen(currentWeightDisplay);
// }

// void showInputsMenu() {
//   lcd.clear();
//   lcd.setCursor(0, 0);
//   lcd.print("A: Set Weight");
//   lcd.setCursor(0, 1);
//   lcd.print("B: Set Feed Times");
//   lcd.setCursor(0, 2);
//   lcd.print("C: Back  *: Reset");
//   lcd.setCursor(0, 3);
//   displayTimeOnLCD();
// }

// void showWeightInput() {
//   lcd.clear();
//   lcd.setCursor(0, 0);
//   lcd.print("Enter Weight (g):");
//   lcd.setCursor(0, 1);
//   lcd.print("Input: ");
//   lcd.print(inputWeight);
//   lcd.print("g      ");
//   lcd.setCursor(0, 2);
//   lcd.print("Press # to confirm");
//   lcd.setCursor(0, 3);
//   displayTimeOnLCD();
// }

// void showTimeInput(int slot) {
//   lcd.clear();
//   lcd.setCursor(0, 0);
//   lcd.print("Feed Time ");
//   lcd.print(slot);
//   lcd.print(" (HHMM):");
//   lcd.setCursor(0, 1);
//   lcd.print("Input: ");
//   lcd.print(inputTime);
//   lcd.print("      ");
//   lcd.setCursor(0, 2);
//   lcd.print("Press # to confirm");
//   lcd.setCursor(0, 3);
//   displayTimeOnLCD();
// }

// void showTimeConfirmed(int slot, int h, int m) {
//   lcd.clear();
//   lcd.setCursor(0, 0);
//   lcd.print("Feed Time ");
//   lcd.print(slot);
//   lcd.print(" Set!");
//   lcd.setCursor(0, 1);
//   if (h < 10) lcd.print("0");
//   lcd.print(h);
//   lcd.print(":");
//   if (m < 10) lcd.print("0");
//   lcd.print(m);
//   lcd.setCursor(0, 3);
//   displayTimeOnLCD();
//   delay(1500);
// }

// void resetAll() {
//   inputWeight = "";
//   targetWeight = 0;
//   feedTime1 = -1;
//   feedTime2 = -1;
//   inputTime = "";
//   timeInputStage = 0;
//   tempHours = 0;
//   tempMinutes = 0;
//   currentState = DEFAULT_SCREEN;
  
//   lcd.clear();
//   lcd.setCursor(0, 0);
//   lcd.print("System Reset!");
//   lcd.setCursor(0, 1);
//   lcd.print("All values cleared");
//   delay(1500);
//   showDefaultScreen();
// }

// void checkFeedingTime() {
//   int currentMinutes = hours * 60 + minutes;
  
//   if (feedTime1 >= 0 && currentMinutes == feedTime1) {
//     lcd.setCursor(0, 0);
//     lcd.print("FEED TIME 1!      ");
//     Serial.println("FEED TIME 1 TRIGGERED!");
//   }
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

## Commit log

2026-06-12 load cell calibrator added
2026-06-12 loadcell calibrater added
2026-07-04 added load cell container servo
2026-07-05 dual loadcell calibration added
2026-09-16 add stl files and demo video
    [P1_Down.stl, P1_middle.stl, P1_name.stl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]
